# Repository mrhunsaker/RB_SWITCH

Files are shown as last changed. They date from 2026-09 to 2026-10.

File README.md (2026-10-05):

# RB Switch









The RB Switch is a three-button Bluetooth Low Energy (BLE) accessibility switch. It presents itself to a computer, tablet, or phone as a standard Bluetooth keyboard, so it works with Switch Control (iOS/iPadOS), Switch Access (Android), and any app that accepts keyboard input.

## At a glance

| | |
|---|---|
| **Buttons** | SW1 Left Arrow, SW2 Enter, SW3 Right Arrow |
| **Bluetooth name** | RB Switch |
| **Microcontroller** | ESP32-S3-MINI-1-N4R2 |
| **Power** | USB-C or a single-cell Li-Po battery. No power switch and no sleep mode. |
| **Charging** | MCP73831, about 500 mA. D1 lights while charging. |
| **Regulator** | TPS63001 3.3 V buck-boost |
| **PCB** | KiCad 10, 4 layers, 115 × 38 mm |
| **Firmware** | Arduino sketch using NimBLE-Arduino 2.x |

## Quick start

1. Power the switch from USB-C or its battery.
2. Pair **RB Switch** in the device's Bluetooth settings.
3. Press each button in a text field: Left, Enter, Right.
4. Set up Switch Control (iOS/iPadOS) or Switch Access (Android) from the guides below.

**Important for Android users:** Android's Switch Access is a separate app you install/update from the Google Play Store, and its setup wizard only offers a one-switch or two-switch configuration. It does not offer a third switch by default. Using the RB Switch's third button on Android requires one extra step beyond the wizard. This is different from iOS/iPadOS, where all three buttons can be assigned directly in the normal setup flow. See [Android Switch Access](docs/switch-access-android.md) and [iOS/iPadOS Switch Control](docs/switch-control-ios.md) before you configure a device.

## Production firmware

The production firmware is:

`firmware/RB_SWITCH_firmware/RB_SWITCH_firmware.ino`

### Button mapping

| Switch | GPIO | Keyboard key |
| --- | ---:| --- |
| SW1 | GPIO10 | Left Arrow |
| SW2 | GPIO11 | Enter |
| SW3 | GPIO12 | Right Arrow  |

Each button press produces one key press followed by one key release. Holding a button does not repeat the key. A press made while no host is connected is ignored.

### Building the firmware

1. Install the Arduino IDE, the **ESP32 Arduino core** by Espressif, and **NimBLE-Arduino 2.x**.
2. Select **ESP32S3 Dev Module** and set **USB CDC On Boot** to **Enabled**.
3. Open the `.ino` file, click **Verify**, then **Upload** over a data-capable USB-C cable. If the upload does not start, hold BOOT, tap RESET, release BOOT.
4. Open the Serial Monitor at 115200 baud.

See [Firmware](docs/firmware.md) for details.

## Documentation

| For | Read |
|---|---|
| Classroom staff setting up a device | [Setup & Pairing](docs/setup.md) |
| iPad and iPhone | [iOS/iPadOS Switch Control](docs/switch-control-ios.md) |
| Android phones and tablets | [Android Switch Access](docs/switch-access-android.md) |
| How the buttons behave | [Switch Operation](docs/use.md) |
| Something is not working | [Troubleshooting](docs/troubleshooting.md) |
| Evaluating a student for switch access and teaching switch skills | [Switch Evaluation Package](docs/evaluation-package.md) |
| Programming the board | [Firmware](docs/firmware.md), [Firmware Customization](docs/firmware-customization.md) |
| Hardware reference | [Hardware](docs/hardware.md) |
| Enclosure label | [QR Code](docs/qr-code.md) |

Published documentation: <https://mrhunsaker.github.io/RB_SWITCH/>

Two printable Word documents are also available. Both are generated from the matching page in `docs/`.

| Download | Source page | Use |
|---|---|---|
| [`RB_Switch_Paraprofessional_Setup_Guide.docx`](RB_Switch_Paraprofessional_Setup_Guide.docx) | `docs/setup.md` | Classroom quick-reference for pairing, setup and troubleshooting |
| [`RB_Switch_Evaluation_Package.docx`](RB_Switch_Evaluation_Package.docx) | `docs/evaluation-package.md` | Fill-in package for evaluating, teaching and documenting adaptive switch access (checklists, five-stage data sheets, graphing sheet, summary report, IEP goal bank) |

## Troubleshooting at a glance

| Symptom | First thing to try |
|---|---|
| Not in the Bluetooth list | Check power; turn Bluetooth off on other nearby devices that were paired before |
| Listed but will not connect | Forget RB Switch on the device and pair again |
| Connected, but no button works | Check it still shows Connected; a press made while disconnected is lost |
| Only two buttons work on Android | Assign the third switch under Assign switches for scanning |
| Will not power on | Charge from USB-C for 30 minutes with a known-good cable |
| Upload fails or no serial port | Hold BOOT, tap RESET, release BOOT; use a data cable |

The full guide, including board-level checks for technicians, is in [Troubleshooting](docs/troubleshooting.md).

## Hardware

The current board uses:

- ESP32-S3-MINI-1-N4R2
- Three Omron B3F-series tactile switches
- USB-C power/programming connection (native USB, no USB-to-serial chip)
- Single-cell Li-Po battery connection and MCP73831 charger
- TPS63001 3.3 V buck-boost regulator
- Battery-voltage sensing (not yet used by the firmware)
- MCP73831 charge-status LED
- Reset and boot buttons, with a 10 kΩ pull-up and 1 µF capacitor on the reset line

Hardware source files are in `electrical/`, `bom/`, and `mechanical/`.

| Path | Contents |
|---|---|
| `electrical/mechanical_switch/RB_Switch.kicad_sch`, `.kicad_pcb` | Current KiCad 10 schematic and 4-layer PCB. The schematic is fully wired and its netlist matches the PCB. |
| `electrical/mechanical_switch/VERIFICATION.md` | How the board was checked against the firmware, and what was not checked |
| `electrical/mechanical_switch/net_table.json` | Net-by-net list of pads |
| `bom/` | BOMs and placement files for JLCPCB and PCBWay, plus sourcing notes |
| `mechanical/` | Enclosure (OpenSCAD) |
| `docs/hardware.md` | Pin map and a part-by-part description of the connections |

> **Before ordering boards:** the files in `electrical/mechanical_switch/gerbers/` and the PCB images in `electrical/mechanical_switch/diagrams/` come from an earlier layout. Re-export them with `create_gerber.ps1` and check the CPL orientation of U1, REG1, D1, J_USB1, and L1 in the fab's preview.

## Production scope

The production design has three mechanical switch inputs only. It does not implement touch sensors, proximity sensors, NeoPixel/RGB indicators, mono-jack inputs, or the earlier F-key input mapping.

The charge-status LED (D1) is controlled by the battery charger and is not a programmable RGB LED.

## Repository layout

| Path | Contents |
|---|---|
| `firmware/RB_SWITCH_firmware/` | Production sketch |
| `firmware/BLE_ADAPTIVE_SWITCH_EXPANDED_SCAFFOLD/` | Archived earlier firmware, not production |
| `electrical/` | KiCad project, gerbers, diagrams, verification notes |
| `bom/` | BOM, placement and sourcing files |
| `mechanical/` | Enclosure and storage box models |
| `docs/` | GitHub Pages source |
| `documents/` | Packaging-friendly copy of `docs/` |
| `tools/` | Scripts that keep `documents/` and the printable Word documents in sync with `docs/` |
| `RB_Switch_Paraprofessional_Setup_Guide.docx` | Printable classroom guide |
| `RB_Switch_Evaluation_Package.docx` | Printable switch evaluation package |
| `CHANGES.md` | Changelog |

## Documentation source

`docs/` is the published GitHub Pages source.

`documents/` contains the same documentation in a packaging-friendly directory. Keep the two documentation sets synchronized when documentation changes.

After editing `docs/`, run:

```
python3 tools/sync_documents.py
node tools/build_docx.js
```

The first script rewrites `documents/` from `docs/`. The second rebuilds both Word documents (`RB_Switch_Paraprofessional_Setup_Guide.docx` from `docs/setup.md` and `RB_Switch_Evaluation_Package.docx` from `docs/evaluation-package.md`). It needs Node.js and the `docx` package (`npm install docx`). Pass `setup` or `evaluation` to build just one. See [tools/README.md](tools/README.md).

## GitHub Pages and enclosure QR code

Publish `docs/` with GitHub Pages. The enclosure QR code should point to the published documentation home page. See [QR Code](docs/qr-code.md).

## Contributing

Contributions to firmware, hardware, and documentation are welcome. See [CONTRIBUTING.md](CONTRIBUTING.md) for project structure, how to propose a change, and pull request expectations, and [CODE_STYLE.md](CODE_STYLE.md) for formatting and naming conventions. Please review [CODE_OF_CONDUCT.md](CODE_OF_CONDUCT.md) before participating.

## Security

To report a suspected security or safety issue, see [SECURITY.md](SECURITY.md) rather than opening a public issue.

## Changelog

See [CHANGES.md](CHANGES.md) for a history of notable changes.

## License

This project is licensed under the APACHE 2.0 License— see [LICENSE](LICENSE) for the full text, including a note on hardware-specific licensing alternatives.

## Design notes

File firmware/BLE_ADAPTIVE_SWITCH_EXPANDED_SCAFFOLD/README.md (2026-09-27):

# Archived Firmware

This directory contains an earlier adaptive-switch firmware implementation retained for historical reference.

It is **not the production RB Switch firmware** and is not part of the current three-button hardware documentation.

## Current production project

Use:

`firmware/RB_SWITCH_firmware/RB_SWITCH_firmware.ino`

The production RB Switch has three mechanical switch inputs:

| Switch | GPIO | Keyboard key |
|---|---:|---|
| SW1 | GPIO10 | Left Arrow |
| SW2 | GPIO11 | Enter |
| SW3 | GPIO12 | Right Arrow |

For current setup, operation, hardware, and firmware instructions, use the repository `README.md` and the `docs/` documentation.

No instructions in this archived directory should be used to configure or manufacture the current production RB Switch.

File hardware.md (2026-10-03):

---
layout: default
title: Hardware Reference
permalink: /hardware.html
---

# Hardware Reference

This page describes the current RB Switch hardware as captured in the KiCad 10 schematic and PCB in `electrical/mechanical_switch/` (4-layer, 115 × 38 mm, last updated 2026-10-03).

The schematic and PCB were checked against each other: all 19 named nets and all 34 intentionally unused pins match pad-for-pad. See `electrical/mechanical_switch/VERIFICATION.md` for what was checked and what was not.

## User controls

| Reference | Function | Net | MCU connection |
|---|---|---|---|
| SW1 | Left Arrow | `/SW1_NET` | U1 pin 14 (IO10) → GPIO10 |
| SW2 | Enter | `/SW2_NET` | U1 pin 15 (IO11) → GPIO11 |
| SW3 | Right Arrow | `/SW3_NET` | U1 pin 16 (IO12) → GPIO12 |
| SW_RST1 | Reset | `/EN_NET` | U1 pin 45 (EN) |
| SW_BOOT1 | Boot / download mode | `/BOOT_NET` | U1 pin 4 (IO0) |

Each of SW1–SW3 connects its GPIO to ground when pressed, so the firmware uses `INPUT_PULLUP` and treats LOW as pressed. Each switch input has a 100 nF capacitor to ground (C9, C10, C11) for filtering. GPIO10–12 are not strapping pins, so a held button at boot does not change boot mode.

Reset and boot use 10 kΩ pull-ups (R5 on EN, R6 on IO0) to 3.3 V, with the switch pulling the line to ground.

## Main electronics

| Reference | Part | Function |
|---|---|---|
| U1 | ESP32-S3-MINI-1-N4R2 | BLE MCU |
| REG1 | TPS63001DRCR | 3.3 V buck-boost regulation |
| L1 | 2.2 µH, Bourns SRN4018 | Regulator inductor |
| U_CHG1 | MCP73831T-2ACI/OT | Li-Po charging |
| J_USB1 | GCT USB4105-GF-A USB-C receptacle | Power, charging and native USB |
| J_BAT1 | JST-PH 2-pin | Battery connection |
| D1 | 0603 red LED | Charge status |
| R7, R8, C8 | 100 kΩ / 100 kΩ / 100 nF | Battery-voltage sense network |

Reference designators `J_BAT1`, `J_USB1`, `SW_RST1`, `SW_BOOT1` and `U_CHG1` end in a digit so KiCad treats them as annotated. Older documents and BOMs may show them without the `1`.

## What each part connects to

**Power input and charging**

- **J_USB1:** VBUS pins (A4, A9, B4, B9) go to C4 and U_CHG1 pin 4. CC1 goes to R3 and CC2 goes to R4. D+ (A6, B6) goes to U1 pin 24 (IO20) and D− (A7, B7) goes to U1 pin 23 (IO19). All GND pins and the shield go to ground. The two SBU pins are unused.
- **R3, R4 (5.1 kΩ):** CC1 and CC2 to ground, so the port presents itself as a USB-C sink.
- **C4 (1 µF):** VBUS to ground.
- **U_CHG1 (MCP73831):** VBUS in, VBAT out to the battery rail, ground, PROG to R1, STAT to D1's cathode.
- **R1 (2 kΩ):** PROG to ground, setting about 500 mA charge current.
- **D1:** cathode to STAT, anode to R2.
- **R2 (1 kΩ):** D1's anode to 3.3 V.

**Battery and regulator**

- **J_BAT1:** pin 1 to the battery rail (VBAT), pin 2 to ground.
- **REG1 (TPS63001):** VIN, VINA and EN go to VBAT. PS/SYNC, PGND, GND and the thermal pad go to ground. L1 and L2 go to the two ends of inductor L1. VOUT and FB go to the 3.3 V rail (the TPS63001 is the fixed 3.3 V version).
- **L1:** between REG1's two switch pins.
- **C1 (10 µF):** VBAT to ground.
- **C2 (22 µF), C3 (10 µF):** 3.3 V rail to ground.

**Battery sensing**

- **R7 and R8 (100 kΩ each):** a divider from VBAT to ground. The midpoint also has C8 (100 nF) to ground and goes to U1 pin 9 (IO5).
- The production firmware does not read this input yet. It reports a fixed 100% battery level.

**Microcontroller**

- **U1:** 3.3 V on pin 3, ground on pins 1, 2, 42, 43 and 46–65 (including the exposed pad). Pins 4, 9, 14, 15, 16, 23, 24 and 45 are connected as described above. The other 32 pins are intentionally unused.
- **C5, C6 (100 nF), C7 (10 µF):** 3.3 V rail to ground, decoupling for U1.

## PCB summary

| Item | Value |
|---|---|
| Size / layers | 115 × 38 mm, 4 layers (F.Cu, In1 = GND plane, In2 = 3V3 plane, B.Cu) |
| Signal routing | 0.2 mm tracks; VBAT, L_A, L_B 0.25 mm; VBUS 0.3 mm |
| Vias | 0.5 mm pad / 0.3 mm drill |
| Fixed placement | SW1–SW3, the two M4 mounting holes (MH1, MH2) and J_USB1 |
| Antenna | The module's antenna end points toward the right edge of the board. That area has a copper keep-out on all layers, and the module's courtyard extends past the board edge. |

SW1, SW2 and SW3 sit at the same positions as in the original design (pad 1 at X = 101, 126, 151 mm; Y = 99 mm). The M4 holes are at (91, 84) and (179.5, 84). J_USB1 is at (84, 99) rotated −90°. All other parts were moved to give the tracks clearance.

MH1 and MH2 have no schematic symbol. Their footprints are marked "Not in schematic" so the parity check does not flag them.

The J_USB1 footprint has a built-in clearance of about 0.18–0.21 mm between its NPTH positioning holes and some pads. The project's minimum hole clearance is set to 0.15 mm for this reason.

## Library notes

- **U1 footprint:** the PCB uses `RF_Module:ESP32-S2-MINI-1`, the land pattern shared with the S3 module. The schematic symbol and BOM identify the part as an ESP32-S3-MINI-1-N4R2. Your KiCad library may report the S3 symbol as not found; this is a library naming issue and does not affect the board.
- **SW1–SW3 footprint:** `Button_Switch_THT:SW_TH_Tactile_Omron_B3F-100x`. Pads 1 are the pair on the top edge and connect to the switch net; pads 2 are the pair on the bottom edge and connect to ground.
- **REG1 footprint:** `Package_SON:Texas_DRC0010J`, without thermal-via pads. Four GND vias sit in the exposed pad.

## Before ordering a board

- The files in `electrical/mechanical_switch/gerbers/` and the PCB images in `electrical/mechanical_switch/diagrams/` were exported from an earlier layout. Run `create_gerber.ps1` to export fresh gerbers and renders before ordering.
- The CPL files in `bom/` were regenerated from the current PCB. Check U1, REG1, D1, J_USB1 and L1 orientation in the fab's placement preview, since no published rotation correction covers them.
- Compare the L1 land pattern with the Bourns SRN4018 datasheet. The board footprint's pad positions differ from the stock KiCad footprint.
- Verify battery polarity: J_BAT1 pin 1 is the positive terminal (VBAT).

## Hardware not included

The current PCB does not include TTP223 touch controllers, proximity sensor hardware, NeoPixel/WS2812 hardware, or 3.5 mm mono-jack switch inputs.

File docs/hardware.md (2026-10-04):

---
layout: default
title: Hardware Reference
permalink: /hardware.html
---

# Hardware Reference

This page describes the current RB Switch hardware as captured in the KiCad 10 schematic and PCB in `electrical/mechanical_switch/` (4-layer, 115 × 38 mm, last updated 2026-10-03).

The schematic and PCB were checked against each other: all 19 named nets and all 34 intentionally unused pins match pad-for-pad. See `electrical/mechanical_switch/VERIFICATION.md` for what was checked and what was not.

## User controls

| Reference | Function | Net | MCU connection |
|---|---|---|---|
| SW1 | Left Arrow | `/SW1_NET` | U1 pin 14 (IO10) → GPIO10 |
| SW2 | Enter | `/SW2_NET` | U1 pin 15 (IO11) → GPIO11 |
| SW3 | Right Arrow | `/SW3_NET` | U1 pin 16 (IO12) → GPIO12 |
| SW_RST1 | Reset | `/EN_NET` | U1 pin 45 (EN) |
| SW_BOOT1 | Boot / download mode | `/BOOT_NET` | U1 pin 4 (IO0) |

Each of SW1–SW3 connects its GPIO to ground when pressed, so the firmware uses `INPUT_PULLUP` and treats LOW as pressed. Each switch input has a 100 nF capacitor to ground (C9, C10, C11) for filtering. GPIO10–12 are not strapping pins, so a held button at boot does not change boot mode.

Reset and boot use 10 kΩ pull-ups (R5 on EN, R6 on IO0) to 3.3 V, with the switch pulling the line to ground. C12 (1 µF) from EN to ground forms an RC delay with R5 (about 10 ms), so the module stays in reset until the 3.3 V rail has settled. This is the same arrangement Espressif uses on its development boards.

## Main electronics

| Reference | Part | Function |
|---|---|---|
| U1 | ESP32-S3-MINI-1-N4R2 | BLE MCU |
| REG1 | TPS63001DRCR | 3.3 V buck-boost regulation |
| L1 | 2.2 µH, Bourns SRN4018 | Regulator inductor |
| U_CHG1 | MCP73831T-2ACI/OT | Li-Po charging |
| J_USB1 | GCT USB4105-GF-A USB-C receptacle | Power, charging and native USB |
| J_BAT1 | JST-PH 2-pin | Battery connection |
| D1 | 0603 red LED | Charge status |
| R7, R8, C8 | 100 kΩ / 100 kΩ / 100 nF | Battery-voltage sense network |
| R5, C12 | 10 kΩ / 1 µF | EN pull-up and reset-delay capacitor |

Reference designators `J_BAT1`, `J_USB1`, `SW_RST1`, `SW_BOOT1` and `U_CHG1` end in a digit so KiCad treats them as annotated. Older documents and BOMs may show them without the `1`.

## What each part connects to

**Power input and charging**

- **J_USB1:** VBUS pins (A4, A9, B4, B9) go to C4 and U_CHG1 pin 4. CC1 goes to R3 and CC2 goes to R4. D+ (A6, B6) goes to U1 pin 24 (IO20) and D− (A7, B7) goes to U1 pin 23 (IO19). All GND pins and the shield go to ground. The two SBU pins are unused.
- **R3, R4 (5.1 kΩ):** CC1 and CC2 to ground, so the port presents itself as a USB-C sink.
- **C4 (1 µF):** VBUS to ground.
- **U_CHG1 (MCP73831):** VBUS in, VBAT out to the battery rail, ground, PROG to R1, STAT to D1's cathode.
- **R1 (2 kΩ):** PROG to ground, setting about 500 mA charge current.
- **D1:** cathode to STAT, anode to R2.
- **R2 (1 kΩ):** D1's anode to 3.3 V.

**Battery and regulator**

- **J_BAT1:** pin 1 to the battery rail (VBAT), pin 2 to ground.
- **REG1 (TPS63001):** VIN, VINA and EN go to VBAT. PS/SYNC, PGND, GND and the thermal pad go to ground. L1 and L2 go to the two ends of inductor L1. VOUT and FB go to the 3.3 V rail (the TPS63001 is the fixed 3.3 V version).
- **L1:** between REG1's two switch pins.
- **C1 (10 µF):** VBAT to ground.
- **C2 (22 µF), C3 (10 µF):** 3.3 V rail to ground.

**Battery sensing**

- **R7 and R8 (100 kΩ each):** a divider from VBAT to ground. The midpoint also has C8 (100 nF) to ground and goes to U1 pin 9 (IO5).
- The production firmware does not read this input yet. It reports a fixed 100% battery level.

**Microcontroller**

- **U1:** 3.3 V on pin 3, ground on pins 1, 2, 42, 43 and 46–65 (including the exposed pad). Pins 4, 9, 14, 15, 16, 23, 24 and 45 are connected as described above. The other 32 pins are intentionally unused.
- **C5, C6 (100 nF), C7 (10 µF):** 3.3 V rail to ground, decoupling for U1.
- **C12 (1 µF):** EN (pin 45) to ground, the reset-delay capacitor described above.

## PCB summary

| Item | Value |
|---|---|
| Size / layers | 115 × 38 mm, 4 layers (F.Cu, In1 = GND plane, In2 = 3V3 plane, B.Cu) |
| Signal routing | 0.2 mm tracks; VBAT, L_A, L_B 0.25 mm; VBUS 0.3 mm |
| Vias | 0.5 mm pad / 0.3 mm drill |
| Fixed placement | SW1–SW3, the two M4 mounting holes (MH1, MH2) and J_USB1 |
| Antenna | The module's antenna end points toward the right edge of the board. That area has a copper keep-out on all layers, and the module's courtyard extends past the board edge. |

SW1, SW2 and SW3 sit at the same positions as in the original design (pad 1 at X = 101, 126, 151 mm; Y = 99 mm). The M4 holes are at (91, 84) and (179.5, 84). J_USB1 is at (84, 99) rotated −90°. All other parts were moved to give the tracks clearance.

MH1 and MH2 have no schematic symbol. Their footprints are marked "Not in schematic" so the parity check does not flag them.

The J_USB1 footprint has a built-in clearance of about 0.18–0.21 mm between its NPTH positioning holes and some pads. The project's minimum hole clearance is set to 0.15 mm for this reason.

## Library notes

- **U1 footprint:** the PCB uses `RF_Module:ESP32-S2-MINI-1`, the land pattern shared with the S3 module. The schematic symbol and BOM identify the part as an ESP32-S3-MINI-1-N4R2. Your KiCad library may report the S3 symbol as not found; this is a library naming issue and does not affect the board.
- **SW1–SW3 footprint:** `Button_Switch_THT:SW_TH_Tactile_Omron_B3F-100x`. Pads 1 are the pair on the top edge and connect to the switch net; pads 2 are the pair on the bottom edge and connect to ground.
- **L1 footprint:** `Inductor_SMD:L_Bourns-SRN4018`. Its pads (1.5 × 3.6 mm, 4.55 mm overall width) match the recommended layout in the Bourns SRN4018 datasheet. The SRN4018-2R2M is at most 1.88 mm tall, well under the enclosure's clearance above the board.
- **REG1 footprint:** `Package_SON:Texas_DRC0010J`, without thermal-via pads. Four GND vias sit in the exposed pad.

## Debugging a board

Measurement points, expected voltages and a symptom guide are in [Troubleshooting, Section 6]({{ '/troubleshooting.html#6-board-level-checks-for-technicians' | relative_url }}).

## Before ordering a board

- The files in `electrical/mechanical_switch/gerbers/` and the PCB images in `electrical/mechanical_switch/diagrams/` were exported from an earlier layout. Run `create_gerber.ps1` to export fresh gerbers and renders before ordering.
- The CPL files in `bom/` were regenerated from the current PCB. Check U1, REG1, D1, J_USB1 and L1 orientation in the fab's placement preview, since no published rotation correction covers them.
- Verify battery polarity: J_BAT1 pin 1 is the positive terminal (VBAT).

## Hardware not included

The current PCB does not include TTP223 touch controllers, proximity sensor hardware, NeoPixel/WS2812 hardware, or 3.5 mm mono-jack switch inputs.

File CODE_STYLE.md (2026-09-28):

# Code Style

This document describes the conventions used across RB Switch's firmware, documentation, and hardware source files. It reflects the style already used in the production sketch and published docs — match what's already there rather than introducing a new convention, unless you're proposing a repo-wide change (open an issue first; see `CONTRIBUTING.md`).

## Firmware (`.ino` / C++)

- **Naming:**
  - Constants use `UPPER_SNAKE_CASE` with `static constexpr`, typed explicitly (`uint8_t`, `uint32_t`), for example: `static constexpr uint8_t SW1_PIN = 10;`.
  - Functions and variables use `camelCase` (`updateSwitch`, `sendKey`, `lastChangeMs`).
  - Types (structs, classes) use `PascalCase` (`SwitchState`, `ServerCallbacks`).
- **Comments:**
  - Use a block comment at the top of the file describing purpose, hardware inputs, and what is deliberately *not* included — this project has a history of scope creep from earlier prototypes, and the header comment is where that boundary is stated (see the existing header for the pattern).
  - Use `// -----...-----` banner comments to separate logical sections (pin map, BLE state, debounce state, BLE setup, switch handling, Arduino setup/loop), matching the existing file.
  - Comment *why*, not just *what*, especially for magic numbers (for example, the existing comment explaining `DEBOUNCE_MS` and the HID Usage ID table above the key constants).
- **Formatting:**
  - Two-space indentation.
  - Braces on the same line as the statement (`if (...) {`), matching the existing file.
  - One statement per line; avoid combining multiple side effects into one line even when C++ allows it.
- **Structure:**
  - Keep `loop()` non-blocking. Avoid adding `delay()` calls inside `loop()` beyond the existing 1 ms yield; use the existing millis()-based debounce pattern (`SwitchState.lastChangeMs`) as the template for any new timed behavior.
  - Keep hardware constants (pins, keys, timing) declared together near the top of the file, not scattered through the logic.
  - Prefer extending the existing `SwitchState` pattern for new inputs over introducing a parallel, differently-shaped mechanism.
- **Scope discipline:** do not add functionality outside the three-mechanical-switch production scope (touch sensors, proximity sensors, NeoPixel/RGB control, mono-jack inputs) to the production sketch. Experimental variants belong in a separate, clearly-labeled directory (see how `firmware/BLE_ADAPTIVE_SWITCH_EXPANDED_SCAFFOLD/` is marked archived), not folded into `RB_SWITCH_firmware.ino`.
- See `docs/firmware-customization.md` for guidance on which specific parts of the file are safe to change.

## Documentation (Markdown)

- **Front matter:** every page in `docs/` starts with:
  ```yaml
  ---
  layout: default
  title: <Page Title>
  permalink: /<slug>.html
  ---
  ```
  The matching page in `documents/` omits the `permalink` line (see `CONTRIBUTING.md` for why the two directories differ).
- **Headings:** one `#` H1 matching the page title, then `##` for major sections, `###` for subsections. Don't skip levels.
- **Cross-links:**
  - In `docs/`, link to other pages with `[Label]({{ '/slug.html' | relative_url }})` (add `#anchor` inside the quoted string if linking to a section).
  - In `documents/`, link with plain `[Label](slug.md)`.
- **Tables** for any fixed mapping (pin/key tables, comparison tables, HID Usage ID references) rather than prose lists — this project documents several small fixed mappings, and tables scan faster for the classroom staff and technicians who are this project's primary documentation audience.
- **Numbered steps** for anything the reader performs in order (pairing, wizard steps); **bullet lists** for unordered facts or checklists (battery-safety checklist, "what's not included" lists).
- **Troubleshooting entries** are phrased as a short symptom heading (`## Button repeats unexpectedly`) followed by either numbered diagnostic steps or a bullet checklist — not narrative prose.
- **Bold** is used for UI labels the reader taps or clicks (`**Settings → Accessibility → Switch Access**`), and for the specific button/action being referenced (`**SW1**`, `**Select**`). Avoid bolding entire sentences.
- **Platform accuracy:** when documenting OS-level accessibility menu steps (Switch Access, Switch Control, or similar), verify against a current, dated source rather than memory before publishing — these menus change between OS releases, and stale steps are worse than no steps. Note menu-wording variance explicitly rather than presenting one OEM's wording as universal.
- **Keep `docs/` and `documents/` synchronized.** See `CONTRIBUTING.md`.

## Hardware sources

- **KiCad (`electrical/`):** keep reference designators consistent with the schematic when adding parts (next available number in the existing series, for example `R9` if `R8` is the highest resistor reference). Regenerate gerbers from the same KiCad project version noted in the PR rather than hand-editing Gerber files.
- **OpenSCAD (`mechanical/`):** name revision files with an explicit revision suffix (matching the existing `enclosure_mechanical_RevD2.scad` pattern) rather than overwriting a prior revision in place, so past revisions remain buildable for reference.
- **BOM (`bom/`):** keep reference designators and part values consistent with the schematic; update the BOM in the same pull request as any schematic change that adds, removes, or substitutes a part.

## Commit messages and pull requests

See the "Submitting a pull request" and "Commit messages" sections of `CONTRIBUTING.md`.

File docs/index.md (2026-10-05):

---
layout: default
title: RB Switch
---

# RB Switch

The **RB Switch** is a three-button Bluetooth Low Energy (BLE) accessibility switch. It presents itself to a computer, tablet, or phone as a standard Bluetooth keyboard, so it works with Switch Control (iOS/iPadOS), Switch Access (Android), and any app that accepts keyboard input.

## Button functions

| Physical switch | MCU GPIO | Keyboard key |
|---|---:|---|
| **SW1** (left) | GPIO10 | **Left Arrow** |
| **SW2** (center) | GPIO11 | **Enter** |
| **SW3** (right) | GPIO12 | **Right Arrow** |

Each button press sends one key press followed by one key release. Holding a button does not repeat the key.

## Quick start

1. Power the RB Switch using USB-C or the installed single-cell Li-Po battery. There is no power switch; it is on whenever it has power.
2. Open Bluetooth settings on the device you want to use.
3. Select **RB Switch**.
4. Complete pairing if prompted.
5. Test SW1, SW2, and SW3 in a text field.
6. If using Switch Control (iOS/iPadOS) or Switch Access (Android), add the buttons as external switches. **Android and iOS/iPadOS handle a 3-button switch differently**. See [Setup & Pairing]({{ '/setup.html' | relative_url }}) before you configure scanning.

Something not working? Go to [Troubleshooting]({{ '/troubleshooting.html' | relative_url }}).

## Which page do I need?

| I am… | Start with |
|---|---|
| A paraprofessional or teacher setting up a student's device | [Setup & Pairing]({{ '/setup.html' | relative_url }}) (a printable version is available on that page) |
| Setting up an iPad or iPhone | [iOS/iPadOS Switch Control]({{ '/switch-control-ios.html' | relative_url }}) |
| Setting up an Android phone or tablet | [Android Switch Access]({{ '/switch-access-android.html' | relative_url }}) |
| Looking for how the buttons behave | [Switch Operation]({{ '/use.html' | relative_url }}) |
| Fixing a problem | [Troubleshooting]({{ '/troubleshooting.html' | relative_url }}) |
| Evaluating a student for switch access, or teaching and documenting switch skills | [Switch Evaluation Package]({{ '/evaluation-package.html' | relative_url }}) (a printable Word version is available on that page) |
| Programming the board | [Firmware]({{ '/firmware.html' | relative_url }}) and [Firmware Customization]({{ '/firmware-customization.html' | relative_url }}) |
| Building, repairing, or ordering boards | [Hardware]({{ '/hardware.html' | relative_url }}) |
| Printing the enclosure label | [QR Code]({{ '/qr-code.html' | relative_url }}) |

## Current hardware

The current board uses an ESP32-S3-MINI-1-N4R2, three Omron B3F-series tactile switches, USB-C, a Li-Po battery connection and charger, a 3.3 V buck-boost regulator, battery-voltage sensing, and a charger-status LED.

The production design has three mechanical switch inputs. Touch sensors, proximity sensors, NeoPixel/RGB indicators, mono-jack inputs, and legacy F-key mappings are not part of the production design.

## Documentation

- [Setup & Pairing]({{ '/setup.html' | relative_url }})
- [Android Switch Access]({{ '/switch-access-android.html' | relative_url }})
- [iOS/iPadOS Switch Control]({{ '/switch-control-ios.html' | relative_url }})
- [Switch Operation]({{ '/use.html' | relative_url }})
- [Firmware]({{ '/firmware.html' | relative_url }})
- [Firmware Customization]({{ '/firmware-customization.html' | relative_url }})
- [Hardware]({{ '/hardware.html' | relative_url }})
- [Troubleshooting]({{ '/troubleshooting.html' | relative_url }})
- [Switch Evaluation Package]({{ '/evaluation-package.html' | relative_url }})
- [QR Code]({{ '/qr-code.html' | relative_url }})

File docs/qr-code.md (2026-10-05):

---
layout: default
title: QR Code
permalink: /qr-code.html
---

# QR Code for the RB Switch

The enclosure QR code should open the published RB Switch documentation home page.

## QR destination

Use the final GitHub Pages URL for this repository:

`https://mrhunsaker.github.io/RB_SWITCH/`

The QR code should point to the published home page, not a local development address or temporary file. If the repository is renamed or moved, regenerate the code and update this page.

## Home page contents

The home page links to Setup & Pairing, Switch Operation, Firmware, Hardware, Troubleshooting, the Switch Evaluation Package, and this QR Code page.

## Enclosure label

A suitable label is:

**RB Switch**  
**Scan for instructions**

Place the QR code where it can be scanned without opening the enclosure.

## Printing tips

- Print the code at least 20 mm × 20 mm, with a blank margin of at least 4 modules (the small squares) on every side.
- Use black on white, or very dark on very light. Avoid low-contrast colors and glossy finishes that reflect light.
- Use a medium or high error-correction level so the code still scans if the label is scuffed.
- Test the finished label with at least one iPhone camera and one Android camera before attaching it.
- Keep the label flat. Avoid placing it over a seam or a curved edge.

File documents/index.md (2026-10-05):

---
layout: default
title: RB Switch
---

# RB Switch

The **RB Switch** is a three-button Bluetooth Low Energy (BLE) accessibility switch. It presents itself to a computer, tablet, or phone as a standard Bluetooth keyboard, so it works with Switch Control (iOS/iPadOS), Switch Access (Android), and any app that accepts keyboard input.

## Button functions

| Physical switch | MCU GPIO | Keyboard key |
|---|---:|---|
| **SW1** (left) | GPIO10 | **Left Arrow** |
| **SW2** (center) | GPIO11 | **Enter** |
| **SW3** (right) | GPIO12 | **Right Arrow** |

Each button press sends one key press followed by one key release. Holding a button does not repeat the key.

## Quick start

1. Power the RB Switch using USB-C or the installed single-cell Li-Po battery. There is no power switch; it is on whenever it has power.
2. Open Bluetooth settings on the device you want to use.
3. Select **RB Switch**.
4. Complete pairing if prompted.
5. Test SW1, SW2, and SW3 in a text field.
6. If using Switch Control (iOS/iPadOS) or Switch Access (Android), add the buttons as external switches. **Android and iOS/iPadOS handle a 3-button switch differently**. See [Setup & Pairing](setup.md) before you configure scanning.

Something not working? Go to [Troubleshooting](troubleshooting.md).

## Which page do I need?

| I am… | Start with |
|---|---|
| A paraprofessional or teacher setting up a student's device | [Setup & Pairing](setup.md) (a printable version is available on that page) |
| Setting up an iPad or iPhone | [iOS/iPadOS Switch Control](switch-control-ios.md) |
| Setting up an Android phone or tablet | [Android Switch Access](switch-access-android.md) |
| Looking for how the buttons behave | [Switch Operation](use.md) |
| Fixing a problem | [Troubleshooting](troubleshooting.md) |
| Evaluating a student for switch access, or teaching and documenting switch skills | [Switch Evaluation Package](evaluation-package.md) (a printable Word version is available on that page) |
| Programming the board | [Firmware](firmware.md) and [Firmware Customization](firmware-customization.md) |
| Building, repairing, or ordering boards | [Hardware](hardware.md) |
| Printing the enclosure label | [QR Code](qr-code.md) |

## Current hardware

The current board uses an ESP32-S3-MINI-1-N4R2, three Omron B3F-series tactile switches, USB-C, a Li-Po battery connection and charger, a 3.3 V buck-boost regulator, battery-voltage sensing, and a charger-status LED.

The production design has three mechanical switch inputs. Touch sensors, proximity sensors, NeoPixel/RGB indicators, mono-jack inputs, and legacy F-key mappings are not part of the production design.

## Documentation

- [Setup & Pairing](setup.md)
- [Android Switch Access](switch-access-android.md)
- [iOS/iPadOS Switch Control](switch-control-ios.md)
- [Switch Operation](use.md)
- [Firmware](firmware.md)
- [Firmware Customization](firmware-customization.md)
- [Hardware](hardware.md)
- [Troubleshooting](troubleshooting.md)
- [Switch Evaluation Package](evaluation-package.md)
- [QR Code](qr-code.md)

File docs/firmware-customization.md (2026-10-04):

---
layout: default
title: Firmware Customization
permalink: /firmware-customization.html
---

# Firmware Customization

This page is for anyone who needs to change what `RB_SWITCH_firmware.ino` actually does — remap a key, change debounce timing, rename the Bluetooth device, or adapt the firmware to a specific student's needs. If you only need to **install** the unmodified production firmware, see [Firmware]({{ '/firmware.html' | relative_url }}) instead. If you need to set up switch **scanning software** on the receiving device, see [Setup & Pairing]({{ '/setup.html' | relative_url }}).

This page assumes you have already installed the Arduino IDE, the ESP32 Arduino core, and the NimBLE-Arduino library, and that you can already open, verify, and upload the unmodified production sketch (see [Firmware]({{ '/firmware.html' | relative_url }})).

## Before you change anything

- Work from a copy. Duplicate `firmware/RB_SWITCH_firmware/RB_SWITCH_firmware.ino` into a new sketch folder (Arduino requires the `.ino` file name to match its parent folder name) rather than editing the production file in place, unless you intend the change to become the new production behavior.
- Change one thing at a time, re-verify, re-upload, and re-test with the Serial Monitor before making a second change. The firmware is small and single-purpose; most bugs come from stacking several changes before testing any of them.
- Keep a copy of the original file. If you're using git, commit before you start editing so you can diff or revert.

## Map of the file

| Section | What it controls | Typically safe to change? |
|---|---|---|
| `SW1_PIN`, `SW2_PIN`, `SW3_PIN` constants | Which GPIO each switch reads | Yes, if you also update the wiring/schematic to match |
| `LEFT_ARROW`, `ENTER_KEY`, `RIGHT_ARROW` constants | Which HID key each switch sends | Yes — this is the most common customization |
| `DEBOUNCE_MS` constant | How long a signal must be stable before it counts as a press | Yes, in small increments |
| `SwitchState sw1/sw2/sw3` struct instances | Binds each pin to its key and debounce state | Yes, alongside the constants above |
| `sendKey()` | Builds and sends the BLE HID press/release report, including the 20 ms hold between them | Only with care — see [Changing the key-hold timing](#changing-the-key-hold-timing) |
| `setupBLE()` | Device name, advertised HID service, report descriptor, power level | Only the device name and power level are routine changes — see below |
| `updateSwitch()` | Debounce and edge-detection logic | Not recommended unless you understand the state machine; changing this can reintroduce switch bounce |
| `setup()` / `loop()` | Pin modes, startup logging, main loop | Safe to add serial logging; avoid adding blocking `delay()` calls inside `loop()` |

## Common customization: remapping a key

The three constants near the top of the file are the usual starting point:

```cpp
static constexpr uint8_t LEFT_ARROW  = 0x50;
static constexpr uint8_t ENTER_KEY   = 0x28;
static constexpr uint8_t RIGHT_ARROW = 0x4F;
```

These are USB HID Usage IDs, not ASCII characters. To remap a button, replace the constant with a different Usage ID and, if you want the name to keep making sense, rename the constant and the comments that reference it. A short reference of commonly useful codes:

| Key | HID Usage ID |
|---|---:|
| Enter / Return | `0x28` |
| Escape | `0x29` |
| Tab | `0x2B` |
| Space | `0x2C` |
| Right Arrow | `0x4F` |
| Left Arrow | `0x50` |
| Down Arrow | `0x51` |
| Up Arrow | `0x52` |
| A–Z | `0x04`–`0x1D` (A=0x04, B=0x05, … Z=0x1D) |
| 1–0 (top row) | `0x1E`–`0x27` |

For the full table, search for "USB HID Usage Tables" (Usage Page 0x07, Keyboard/Keypad) — the constants above are drawn directly from that specification, and the firmware's report descriptor already declares the full `0x00`–`0x73` range as valid, so most standard keys work without changing `setupBLE()`.

**Why you might do this:** the most common reason is adapting the RB Switch to a specific accessibility workflow rather than the default Left Arrow / Enter / Right Arrow text-navigation mapping. For example, some Switch Access or Switch Control configurations read more naturally if the "select" button sends **Space** instead of **Enter**, or if a two-switch Android configuration is simplified by making both remaining buttons send the *same* key (for example, both edge switches send Tab) so that either hand can trigger the same scanning action. If you do this, update `docs/use.md` and `docs/hardware.md` (or your local equivalents) so the documented button map stays accurate — see [Keeping documentation in sync](#keeping-documentation-in-sync).

## Changing debounce timing

```cpp
static constexpr uint32_t DEBOUNCE_MS = 35;
```

This is the minimum time a signal must stay stable before the firmware treats it as a real press. 35 ms is a reasonable default for the Omron B3F-series tactile switches used on the production PCB. If a student's motor pattern causes intermittent double-presses, increasing this value (try 50–75 ms in small steps) is a reasonable first troubleshooting step before assuming a hardware fault. If you increase it substantially (past roughly 100 ms), very fast intentional double-taps may start being merged into one press — test with the actual student, not just yourself.

## Changing the Bluetooth device name

```cpp
NimBLEDevice::init("RB Switch");
...
hid->setManufacturer("RB Switch");
...
advertisementData.setName("RB Switch");
```

All three of these should be changed together (for example, to distinguish two units in the same classroom, such as `"RB Switch 2"`). Every unit advertises as plain "RB Switch" by default, so giving each classroom unit its own name is the simplest way to tell them apart. If you change the name, also update the physical label/sticker on the enclosure and the [QR Code]({{ '/qr-code.html' | relative_url }}) destination if it references the device name, and re-pair any devices that had the old name saved. Also forget the old name on each host and clear the stored pairings on the RB Switch (see [Troubleshooting]({{ '/troubleshooting.html#clearing-the-rb-switchs-stored-pairings' | relative_url }})).

## Changing the key-hold timing

```cpp
delay(20);
```

inside `sendKey()` controls how long the "key down" HID report is held before the "key up" report is sent. 20 ms is well within what any host OS expects for a single keypress. Shortening this is not recommended — some hosts debounce very short HID reports and may drop the keystroke entirely. If a receiving app seems to miss presses under load, try lengthening this value slightly (30–40 ms) before changing anything else.

## Adding a fourth input (advanced)

The production PCB and firmware are deliberately three-switch. If you are prototyping an expansion (for example, testing a 4th mechanical input on a breadboard before considering a hardware revision):

1. Pick an unused GPIO that is not one of GPIO10/11/12, is not already used on the board (GPIO0 BOOT, GPIO5 battery sense, GPIO19/20 USB, EN reset), and is not reserved for USB, flash, or strapping on the ESP32-S3-MINI-1-N4R2 module — check the module's datasheet before choosing.
2. Add a new `SwitchState` instance following the existing `sw1`/`sw2`/`sw3` pattern.
3. Add a matching `pinMode(..., INPUT_PULLUP)` call in `setup()`.
4. Add a matching `updateSwitch(...)` call in `loop()`.
5. Add the new HID Usage ID constant.

This is firmware-only prototyping guidance. It does **not** reflect the production hardware described in [Hardware]({{ '/hardware.html' | relative_url }}), and a fourth input has no footprint on the current PCB. Do not describe a modified sketch as "the production firmware" in documentation, labels, or support conversations — see the "Hardware not included" section of [Hardware]({{ '/hardware.html' | relative_url }}) and the archived-firmware note in `firmware/BLE_ADAPTIVE_SWITCH_EXPANDED_SCAFFOLD/README.md` for why this distinction matters to this project.

## Verifying a change

After any edit:

1. **Verify** (checkmark icon) before uploading, to catch syntax errors early.
2. **Upload** over a data-capable USB-C cable.
3. Open **Serial Monitor** at 115200 baud. Confirm the startup banner still prints the mapping you expect.
4. Press each physical button and confirm the Serial Monitor logs `SW GPIOx -> HID 0xYY` for the GPIO/key pair you intended.
5. Pair with a real host device and repeat the plain-text-field test from [Setup & Pairing, Section 4]({{ '/setup.html#4-test-the-three-buttons' | relative_url }}).
6. Only after that, re-test inside Switch Access or Switch Control if the change affects how the device should be scanned (see [Android Switch Access]({{ '/switch-access-android.html' | relative_url }}) or [iOS/iPadOS Switch Control]({{ '/switch-control-ios.html' | relative_url }})).

If something goes wrong after a change, see [Troubleshooting]({{ '/troubleshooting.html#5-firmware-upload-and-serial-monitor' | relative_url }}).

## Keeping documentation in sync

If a firmware change alters the button mapping, debounce timing, or device name from what's documented, update all of the following so a future maintainer isn't misled by a stale table:

- `README.md`
- `docs/index.md` and `documents/index.md`
- `docs/use.md` and `documents/use.md`
- `docs/setup.md` and `documents/setup.md`, then rebuild `RB_Switch_Paraprofessional_Setup_Guide.docx` (see the README)
- `docs/hardware.md` and `documents/hardware.md` (if the wiring itself changed)
- The firmware's own header comment and `Serial.println()` startup banner

See [CONTRIBUTING.md](https://github.com/mrhunsaker/RB_SWITCH/blob/main/CONTRIBUTING.md) in the repository root for the full documentation-sync expectation for pull requests.

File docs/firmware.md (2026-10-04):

---
layout: default
title: Firmware
permalink: /firmware.html
---

# Firmware

## Production firmware

The production sketch is:

`firmware/RB_SWITCH_firmware/RB_SWITCH_firmware.ino`

The sketch is self-contained and does not require a project-specific header file.

## Required software

For firmware maintenance, install:

- Arduino IDE
- ESP32 Arduino core by Espressif
- NimBLE-Arduino, **version 2.x** (the sketch uses the 2.x callback signatures, so 1.x will not compile)

No touch-sensor, proximity-sensor, NeoPixel, or separate project-specific HID library is required.

## Board selection

For the production ESP32-S3 module, select:

**ESP32 Arduino → ESP32S3 Dev Module**

Use the board settings required by the exact production module.

The board has no separate USB-to-serial chip. USB-C connects directly to the ESP32-S3's native USB (D− on GPIO19, D+ on GPIO20), so firmware is uploaded and the Serial Monitor is read over that same connection. In the Arduino IDE **Tools** menu, set **USB CDC On Boot** to **Enabled** if you want `Serial` output to appear in the Serial Monitor.

## Uploading firmware

1. Connect the PCB with a data-capable USB-C cable.
2. Open `RB_SWITCH_firmware.ino`.
3. Select the ESP32-S3 board and set **USB CDC On Boot** to **Enabled**.
4. Select the correct serial port.
5. Click **Verify**.
6. Click **Upload**.
7. If necessary, enter the ESP32-S3 bootloader: hold BOOT, press and release RESET, then release BOOT.
8. Reset the board after upload.
9. Open the Serial Monitor at 115200 baud and confirm the startup banner appears.
10. Pair with a host and run the three-button test from [Setup & Pairing]({{ '/setup.html#4-test-the-three-buttons' | relative_url }}).

If the upload fails or no serial port appears, see [Troubleshooting]({{ '/troubleshooting.html#5-firmware-upload-and-serial-monitor' | relative_url }}).

## Serial diagnostics

Open the Serial Monitor at **115200 baud**. The firmware reports the three button mappings and logs button activity with its GPIO and HID usage ID. It also prints `BLE connected` and `BLE disconnected; restarting advertising`, and `Key ignored: BLE not connected` when a button is pressed with no host connected. The full expected output is in [Troubleshooting]({{ '/troubleshooting.html#what-the-serial-monitor-should-show' | relative_url }}).

## Hardware the firmware does not use

The board also has a battery-voltage divider on GPIO5 (VBAT ÷ 2) and a charge-status LED (D1) driven by the charger. The production firmware does not read GPIO5 and reports a fixed 100% battery level. See [Hardware]({{ '/hardware.html' | relative_url }}) for the full pin map.

## HID usage IDs

| Function | HID Usage ID |
|---|---:|
| Enter / Return | `0x28` |
| Right Arrow | `0x4F` |
| Left Arrow | `0x50` |

## Bluetooth behavior

- The advertised Bluetooth name is **RB Switch** (the same on every unit).
- The sketch advertises the standard HID service and presents a boot-compatible keyboard.
- Bonding is enabled with no passkey. Pairing data is stored in flash. To clear it, erase flash while uploading (see [Troubleshooting]({{ '/troubleshooting.html#clearing-the-rb-switchs-stored-pairings' | relative_url }})).
- After a disconnect, advertising restarts automatically.
- Transmit power is set to the maximum the sketch requests (`ESP_PWR_LVL_P9`).
- There is no sleep mode, so the device draws power continuously whenever it is powered.

## Modifying the firmware

For remapping keys, changing debounce timing, renaming the device, or other customization of `RB_SWITCH_firmware.ino`, see [Firmware Customization]({{ '/firmware-customization.html' | relative_url }}).

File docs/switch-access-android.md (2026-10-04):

---
layout: default
title: Android Switch Access
permalink: /switch-access-android.html
---

# Android Switch Access with the RB Switch

This page is a deep dive into using the RB Switch's three buttons with Android's **Switch Access** feature. Read [Setup & Pairing]({{ '/setup.html' | relative_url }}) first if you haven't paired the RB Switch yet.

## Why this page exists

The RB Switch has three physical buttons (SW1 = Left Arrow, SW2 = Enter, SW3 = Right Arrow). On **iOS/iPadOS**, all three can be assigned to distinct actions directly through the normal setup flow (see [iOS/iPadOS Switch Control]({{ '/switch-control-ios.html' | relative_url }})). On **Android**, the built-in setup wizard only ever asks you to choose between a **one-switch** or **two-switch** configuration — it does not offer a "three-switch" option. This is a real, current limitation of the guided Switch Access wizard, not a bug in the RB Switch.

The good news: Android **does** support more than two switches — up to **five** — but only through settings that sit outside the wizard. This page shows how to get there.

## 1. Install Switch Access from the Google Play Store

Switch Access is no longer only a hidden feature bundled inside Android Accessibility Suite. Google now distributes it as its **own standalone app** on the Play Store.

1. Open the **Google Play Store** app.
2. Search for **Switch Access**.
3. Install the app (or tap **Update** if it's already installed but out of date).
4. Open **Settings → Accessibility**. Switch Access should now appear under **Downloaded apps** (or simply under **Accessibility**, depending on your Android version and device manufacturer).

If you skip this step, you may still find an older, more limited version of Switch Access already on the device — but it can lag behind the Play Store version in features and bug fixes. Always check the Play Store first, especially on a device that hasn't been updated recently.

## 2. Understand the wizard's one-switch / two-switch choice

After you turn on Switch Access and grant it permission, the setup wizard walks you through:

1. Choosing a switch type — select **Bluetooth switch** for the RB Switch.
2. Selecting your device from the Bluetooth list and confirming pairing.
3. Choosing **One switch** or **Two switch**.
   - **One switch**: press the switch to start scanning; press it again to select the highlighted item (auto-scan).
   - **Two switch** (recommended starting point for the RB Switch): one switch moves ("Next"), the other selects ("Select").
4. Choosing a scanning method: **Linear scanning**, **Row-column scanning**, or **Group selection**.
5. Assigning the RB Switch buttons you want to the **Next** and **Select** roles when prompted.
6. A short practice screen, then **Finish**.

At no point does this wizard ask "do you have a third switch?" That question only exists in the advanced settings screen described next.

## 3. Add the third RB Switch button (Previous)

Once the wizard is finished, go back into the settings by hand:

1. **Settings → Accessibility → Switch Access → Settings.**
2. Confirm **Auto-scan** is off (it should be, if you chose Two switch).
3. Tap **Assign switches for scanning**.
4. You will see **Next** and **Select** already assigned from the wizard. Tap **Previous**.
5. Press the remaining RB Switch button (SW1 / Left Arrow, if you used the recommended mapping below) when prompted.
6. Tap **Save**.

You can assign **up to five total switches** this way — Next, Select, Previous, Group Selection colors, and Auto-scan Reverse are all valid targets, depending on which scanning method you picked in step 4 above. For the RB Switch's three physical buttons, **Next / Select / Previous** is the natural mapping.

### Recommended mapping

| RB Switch button | Sends | Recommended Switch Access action |
|---|---|---|
| SW1 | Left Arrow | **Previous** |
| SW2 | Enter | **Select** |
| SW3 | Right Arrow | **Next** |

This mirrors the button layout printed on the enclosure (left, center, right) and the arrow-key intuition students already have from the plain-keyboard test in [Setup & Pairing]({{ '/setup.html' | relative_url }}).

If a student only needs two functions, it is entirely reasonable to stop after the wizard and leave SW1 unused on that device — nothing else needs to change, and the same RB Switch will still expose all three buttons normally to a computer, Chromebook, or iPad.

## 4. Choosing a scanning method

- **Linear scanning** moves through on-screen items one at a time (or one row at a time on a keyboard). This is the simplest method to explain to a new switch user.
- **Row-column scanning** scans by row first, then by item within the selected row. This is faster once a student is comfortable with two-step selection.
- **Group selection** requires two or more switches and divides the screen into color-coded groups; each press narrows down the selection. This method benefits the most from having a third switch assigned, since more switches mean fewer presses per selection.

Whichever method you choose, re-test all assigned buttons afterward (see [Setup & Pairing, Section 4]({{ '/setup.html#4-test-the-three-buttons' | relative_url }})).

## 5. Adjusting timing and feedback

From **Switch Access Settings**:

- **Speech, sound & vibration → Spoken feedback** reads highlighted items aloud, which can help a student who is still learning the scan pattern.
- Auto-scan timing (delay before the first item, delay between items) is adjustable if you are using the one-switch method.
- **Change Switch Access settings → [action]** lets you review or reassign any button to any action at any time, without re-running the whole wizard.

## 6. Android-specific troubleshooting

**Switch Access doesn't appear under Accessibility at all.**
Install or update the app from the Google Play Store (Step 1). On some devices it will not appear until the app has been opened at least once after installing.

**The wizard only lets me pick one or two switches, and I have three buttons.**
This is expected — see Step 3 above. The wizard is not the place to add a third switch; the **Assign switches for scanning** screen under Switch Access Settings is.

**I assigned Previous to SW1, but pressing it does nothing.**
Confirm you saved the assignment (Step 3, step 6) and that you are testing inside an app while Switch Access scanning is actually active (the screen should show a highlight box). Previous only affects the on-screen highlight; it does not undo an action that was already selected.

**Group Selection colors look confusing with three switches.**
Group Selection is most useful with three or more switches, but it does take practice. Consider starting a new student on Linear or Row-column scanning with just Next/Select, and introducing Previous or Group Selection later.

**A key on the RB Switch does something unexpected inside Switch Access, like opening a menu.**
Left Arrow, Enter, and Right Arrow are ordinary keyboard keys. If another keyboard shortcut on the device is bound to one of those keys outside of Switch Access, it can fire at the same time. Re-check the button assignment in **Assign switches for scanning**, and confirm no other keyboard-shortcut feature is intercepting the same key.

For hardware-level troubleshooting (a specific button not registering at all, on any platform), see [Troubleshooting]({{ '/troubleshooting.html' | relative_url }}).

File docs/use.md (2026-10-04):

---
layout: default
title: Switch Operation
permalink: /use.html
---

# Switch Operation

## Button map

| Button | Keyboard action |
|---|---|
| SW1 (left) | Left Arrow |
| SW2 (center) | Enter |
| SW3 (right) | Right Arrow |

This mapping is fixed in the production firmware.

## Button behavior

When a button is pressed, the firmware:

1. Reads the switch.
2. Debounces the input for 35 ms.
3. Detects the transition from released to pressed.
4. Sends the corresponding BLE HID key press.
5. Sends the corresponding BLE HID key release about 20 ms later.

A held button does not continuously repeat the key. Releasing a button sends nothing.

## Connection behavior

- The RB Switch advertises as **RB Switch** as soon as it has power. The name is the same on every unit.
- While no host is connected, button presses are ignored. They are not stored or sent later.
- If the connection drops, the RB Switch starts advertising again automatically, and a paired host normally reconnects on its own.
- One host uses the RB Switch at a time. To move it to another device, disconnect it from the first device (or turn that device's Bluetooth off), then connect from the new one.
- Pairing is stored in the RB Switch (bonding). No passkey is needed.

## Power

- The RB Switch runs from USB-C or its single-cell Li-Po battery.
- It has no power switch and no sleep mode. It is on whenever it has power.
- It reports a fixed 100% battery level to the host, so the host's battery indicator does not show the real charge.

## Electrical input behavior

The switches connect their GPIO inputs to ground when pressed.

| Signal | GPIO | Input mode | Active state |
|---|---:|---|---|
| SW1_NET | 10 | `INPUT_PULLUP` | LOW |
| SW2_NET | 11 | `INPUT_PULLUP` | LOW |
| SW3_NET | 12 | `INPUT_PULLUP` | LOW |

Each switch input has a 100 nF capacitor for hardware filtering.

## Charge-status LED

D1 is the charge-status LED controlled by the MCP73831 charger. It is on while the battery charges from USB-C and off when charging is complete or USB-C is not connected. It is not a programmable RGB LED, and it does not show button presses or the Bluetooth connection. See [Troubleshooting]({{ '/troubleshooting.html#4-power-charging-and-the-light' | relative_url }}).

## Using these buttons with accessibility scanning

The three buttons above are ordinary keyboard keys. How a host device turns them into scanning actions (Next/Previous/Select and similar) is configured on the host, not the RB Switch. **Android and iOS/iPadOS configure this differently**. See [Setup & Pairing]({{ '/setup.html' | relative_url }}), [Android Switch Access]({{ '/switch-access-android.html' | relative_url }}), and [iOS/iPadOS Switch Control]({{ '/switch-control-ios.html' | relative_url }}).

## Production scope

The current production design contains only the three mechanical switch inputs above. It does not contain or implement touch sensors, proximity sensors, NeoPixel/WS2812 RGB control, mono-jack inputs, eleven-input operation, or F1–F13 legacy mappings.

If something is not working, see [Troubleshooting]({{ '/troubleshooting.html' | relative_url }}).

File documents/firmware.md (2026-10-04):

---
layout: default
title: Firmware
---

# Firmware

## Production firmware

The production sketch is:

`firmware/RB_SWITCH_firmware/RB_SWITCH_firmware.ino`

The sketch is self-contained and does not require a project-specific header file.

## Required software

For firmware maintenance, install:

- Arduino IDE
- ESP32 Arduino core by Espressif
- NimBLE-Arduino, **version 2.x** (the sketch uses the 2.x callback signatures, so 1.x will not compile)

No touch-sensor, proximity-sensor, NeoPixel, or separate project-specific HID library is required.

## Board selection

For the production ESP32-S3 module, select:

**ESP32 Arduino → ESP32S3 Dev Module**

Use the board settings required by the exact production module.

The board has no separate USB-to-serial chip. USB-C connects directly to the ESP32-S3's native USB (D− on GPIO19, D+ on GPIO20), so firmware is uploaded and the Serial Monitor is read over that same connection. In the Arduino IDE **Tools** menu, set **USB CDC On Boot** to **Enabled** if you want `Serial` output to appear in the Serial Monitor.

## Uploading firmware

1. Connect the PCB with a data-capable USB-C cable.
2. Open `RB_SWITCH_firmware.ino`.
3. Select the ESP32-S3 board and set **USB CDC On Boot** to **Enabled**.
4. Select the correct serial port.
5. Click **Verify**.
6. Click **Upload**.
7. If necessary, enter the ESP32-S3 bootloader: hold BOOT, press and release RESET, then release BOOT.
8. Reset the board after upload.
9. Open the Serial Monitor at 115200 baud and confirm the startup banner appears.
10. Pair with a host and run the three-button test from [Setup & Pairing](setup.md#4-test-the-three-buttons).

If the upload fails or no serial port appears, see [Troubleshooting](troubleshooting.md#5-firmware-upload-and-serial-monitor).

## Serial diagnostics

Open the Serial Monitor at **115200 baud**. The firmware reports the three button mappings and logs button activity with its GPIO and HID usage ID. It also prints `BLE connected` and `BLE disconnected; restarting advertising`, and `Key ignored: BLE not connected` when a button is pressed with no host connected. The full expected output is in [Troubleshooting](troubleshooting.md#what-the-serial-monitor-should-show).

## Hardware the firmware does not use

The board also has a battery-voltage divider on GPIO5 (VBAT ÷ 2) and a charge-status LED (D1) driven by the charger. The production firmware does not read GPIO5 and reports a fixed 100% battery level. See [Hardware](hardware.md) for the full pin map.

## HID usage IDs

| Function | HID Usage ID |
|---|---:|
| Enter / Return | `0x28` |
| Right Arrow | `0x4F` |
| Left Arrow | `0x50` |

## Bluetooth behavior

- The advertised Bluetooth name is **RB Switch** (the same on every unit).
- The sketch advertises the standard HID service and presents a boot-compatible keyboard.
- Bonding is enabled with no passkey. Pairing data is stored in flash. To clear it, erase flash while uploading (see [Troubleshooting](troubleshooting.md#clearing-the-rb-switchs-stored-pairings)).
- After a disconnect, advertising restarts automatically.
- Transmit power is set to the maximum the sketch requests (`ESP_PWR_LVL_P9`).
- There is no sleep mode, so the device draws power continuously whenever it is powered.

## Modifying the firmware

For remapping keys, changing debounce timing, renaming the device, or other customization of `RB_SWITCH_firmware.ino`, see [Firmware Customization](firmware-customization.md).

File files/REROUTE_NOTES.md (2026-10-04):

> **Superseded (2026-10-03).** This note describes an earlier routing of the PCB. The current schematic, PCB and checks are in `electrical/mechanical_switch/` and `electrical/mechanical_switch/VERIFICATION.md`. Kept for history only.

# RB_Switch re-route notes

Board: 4-layer, 115 x 38 mm (In1 = GND plane, In2 = V3V3 plane).

## What was wrong
The original file had 36 tracks, each a single straight line from pad to pad (some ~100 mm long, diagonal across the board). 22 pairs crossed on the same layer (real shorts), and 58 vias were stacked on pads with overlapping annuli. Several endpoints did not land on any pad (J_USB tracks started at x=81-86, the pads are at x=87.7).

## What changed in RB_Switch.kicad_pcb
- Removed all 36 tracks and 58 vias (signal-net vias, duplicate vias, and plane vias that violated clearance or sat inside through-hole pads).
- Kept 61 plane vias (GND / V3V3) that were clean.
- Added 235 track segments (17 signal nets) and 45 vias (signal layer hops + plane fan-outs for REG1 pin 1, REG1 GND pins 3/7/9 and the USB-C GND pins).
- Widened VBUS / VBAT / L_A / L_B to 0.3-0.5 mm where clearance allowed (0.2 mm at fine-pitch pads).
- Nothing else in the file was touched (footprints, zones, outline, rules).

## Checked here (custom script, NOT KiCad DRC)
0 copper-clearance errors (0.2 mm), 0 edge-clearance errors (0.5 mm), 0 hole-to-hole errors, all 17 signal nets fully connected.
The script uses rectangular pads and ignores silkscreen, mask, courtyards and zone fill, so KiCad's DRC is the authority.

## Needs your decision: "Antenna" rule area
The rule area (x 154.25-173.75, y 76.3-121.7, all copper layers; no tracks / vias / pads / copper pour / footprints) spans the full board height. It:
- contains D1, R2, R7, C9, C10, C11 and part of SW3, so KiCad will flag them;
- must be crossed by every net between the left-hand circuitry and the ESP32 (SW1/2/3, EN, USB D+/D-, VBAT_SENSE, BOOT), so a route that respects it does not exist;
- removes the GND and V3V3 plane copper there, leaving C9.2, C10.2, C11.2, SW3.2 (GND) and R2.2 (V3V3) without a plane connection.
I routed through it and did not edit it. Shrinking it to the real antenna end of U1 should clear all of the above.

## Other observations
- L1 sits ~30 mm from REG1; the switching-node traces (L_A / L_B) are long for a buck-boost.
- About 60 GND/V3V3 pads have vias directly in the pad. Unless plugged/filled, solder can wick through; tell PCBWay or move the vias.

## Next steps
1. Open the file in KiCad, press B to refill zones, run DRC (with parity check).
2. Decide the Antenna rule area.
3. Re-export with create_gerber.ps1 and upload.

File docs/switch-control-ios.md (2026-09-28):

---
layout: default
title: iOS/iPadOS Switch Control
permalink: /switch-control-ios.html
---

# iOS/iPadOS Switch Control with the RB Switch

This page is a deep dive into using the RB Switch's three buttons with Apple's **Switch Control** accessibility feature on iPhone and iPad. Read [Setup & Pairing]({{ '/setup.html' | relative_url }}) first if you haven't paired the RB Switch yet.

## How this differs from Android

Switch Control is built into iOS/iPadOS — there is no separate app to install from the App Store. More importantly for the RB Switch, **Switch Control does not force a choice between "one switch" and "two switch" the way Android's Switch Access wizard does.** Instead, you add switches one at a time, and each new switch is assigned to whichever action you pick from a full list. Because of this, all three RB Switch buttons can be given three distinct, independent actions from the very first setup pass, with no extra steps required beyond what's already in [Setup & Pairing]({{ '/setup.html' | relative_url }}). If you're coming from an Android Switch Access setup and wondering why there's no equivalent "advanced settings" step here — there isn't one needed. See [Android Switch Access]({{ '/switch-access-android.html' | relative_url }}) for the contrast.

## Turning on Switch Control

1. Pair **RB Switch** in **Settings → Bluetooth** (see [Setup & Pairing]({{ '/setup.html' | relative_url }})).
2. Open **Settings → Accessibility → Switch Control**.
3. Turn on **Switch Control**.

The first time it's enabled, iOS may briefly show an onboarding screen. You can dismiss it and configure switches directly.

## Adding all three RB Switch buttons

1. Open **Switches → Add New Switch → External**.
2. Press the RB Switch button you want to assign first (there's no required order).
3. When prompted, choose the action for that button. Common first choices:
   - **Select Item**
   - **Move to Next Item**
   - **Move to Previous Item**
4. Tap **Add New Switch** again and repeat for the second button.
5. Repeat once more for the third button.

### Recommended mapping

| RB Switch button | Sends | Recommended Switch Control action |
|---|---|---|
| SW1 | Left Arrow | **Move to Previous Item** |
| SW2 | Enter | **Select Item** |
| SW3 | Right Arrow | **Move to Next Item** |

This mirrors the left/center/right layout of the enclosure and the arrow-key intuition students already have from the plain-keyboard test in [Setup & Pairing]({{ '/setup.html' | relative_url }}), and it maps directly onto the equivalent Android recommendation, so a student who uses both an iPad and an Android device gets a consistent physical mapping even though the two operating systems configure it differently.

Switch Control offers many more actions than these three (Long Press, Tap, gestures, scrolling, opening Control Center, running a custom "Recipe," and more). Because assignment is per-switch and not limited to a fixed set of roles, you can give any RB Switch button any of these actions if the default mapping above doesn't fit a particular student.

## Choosing a scanning style

**Settings → Accessibility → Switch Control → Scanning Style** offers:

- **Auto Scanning** — the highlight moves on its own; press a switch to select. Works with as few as one assigned switch.
- **Manual Scanning** — you press one switch to move the highlight and another to select. This is the natural fit for the RB Switch's Left/Right + Enter mapping above.
- **Single Switch Step** — a single switch both moves and (after a pause) selects.

**Auto Scanning** and **Manual Scanning** both make use of a third switch if you've assigned **Move to Previous Item**, letting a student correct an overshoot without waiting for the scan to wrap back around.

## Adjusting timing and feedback

- **Settings → Accessibility → Switch Control → Auto Scanning Time** adjusts how long each item is highlighted before Auto Scanning moves on.
- **Switch Control → Switch Stabilization** and **Switch Control → Ignore Repeat** help filter out accidental double-presses, which can be useful if a student's motor control causes brief bounces (see also the firmware-level debounce described in [Firmware]({{ '/firmware.html' | relative_url }})).
- **Switch Control → Sound Effects** and **Speech** provide audio feedback as the highlight scans, which can help a student learn the pattern before relying on vision alone.

## iOS/iPadOS-specific troubleshooting

**A button is recognized as a keypress but Switch Control never highlights anything.**
Confirm Switch Control is actually turned on (Step 1) — the RB Switch will still send Left Arrow / Enter / Right Arrow to any app whether or not Switch Control is active, which can look like "it's connected but nothing happens" if you're testing inside an app that also responds to arrow keys.

**I want to reassign a button to a different action.**
Open **Switches**, tap the existing switch entry, and choose a new action. You do not need to remove and re-add it.

**Menu wording doesn't match this page.**
Apple periodically renames or relocates Switch Control menu items between iOS/iPadOS releases. The concepts above (Switches → Add New Switch → External, per-switch action assignment, scanning style) have been stable across recent releases even when exact wording shifts.

For hardware-level troubleshooting (a specific button not registering at all, on any platform), see [Troubleshooting]({{ '/troubleshooting.html' | relative_url }}).

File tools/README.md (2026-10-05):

# Documentation tools

Two small scripts keep the documentation copies in sync. Run them from the repository root after editing anything in `docs/`.

| Script | What it does |
|---|---|
| `python3 tools/sync_documents.py` | Rewrites `documents/` from `docs/` (drops the Jekyll `permalink:` line and turns `{{ '/page.html' \| relative_url }}` links into `page.md`). Add `--check` to see whether `documents/` is stale without writing anything. |
| `node tools/build_docx.js [setup\|evaluation]` | Rebuilds the printable Word documents from `docs/`. With no argument it builds both. Needs Node.js and the `docx` package (`npm install docx`). |

## Word documents

| Output | Source |
|---|---|
| `RB_Switch_Paraprofessional_Setup_Guide.docx` | `docs/setup.md` |
| `RB_Switch_Evaluation_Package.docx` | `docs/evaluation-package.md` |

The Markdown page is the single source for each Word file. Do not edit the `.docx` by hand; your changes would be lost the next time it is rebuilt.

Comments in the Markdown control the Word output. They are invisible on the website and on GitHub.

| Comment | Effect in the Word file |
|---|---|
| `<!-- web-only -->` ... `<!-- /web-only -->` | Text between the markers is left out |
| `<!-- pagebreak -->` | Starts a new page |
| `<!-- landscape -->` / `<!-- portrait -->` | Starts a new page in that orientation (the evaluation package uses landscape for its data sheets) |

Other behavior: a blockquote that starts with **Note**, **Important**, **Tip** or **Warning** becomes a colored callout. A line made only of underscores becomes a handwriting line. Table rows that are mostly empty get extra height so they can be filled in by hand.

After rebuilding a Word file, open it and check the page breaks before printing.

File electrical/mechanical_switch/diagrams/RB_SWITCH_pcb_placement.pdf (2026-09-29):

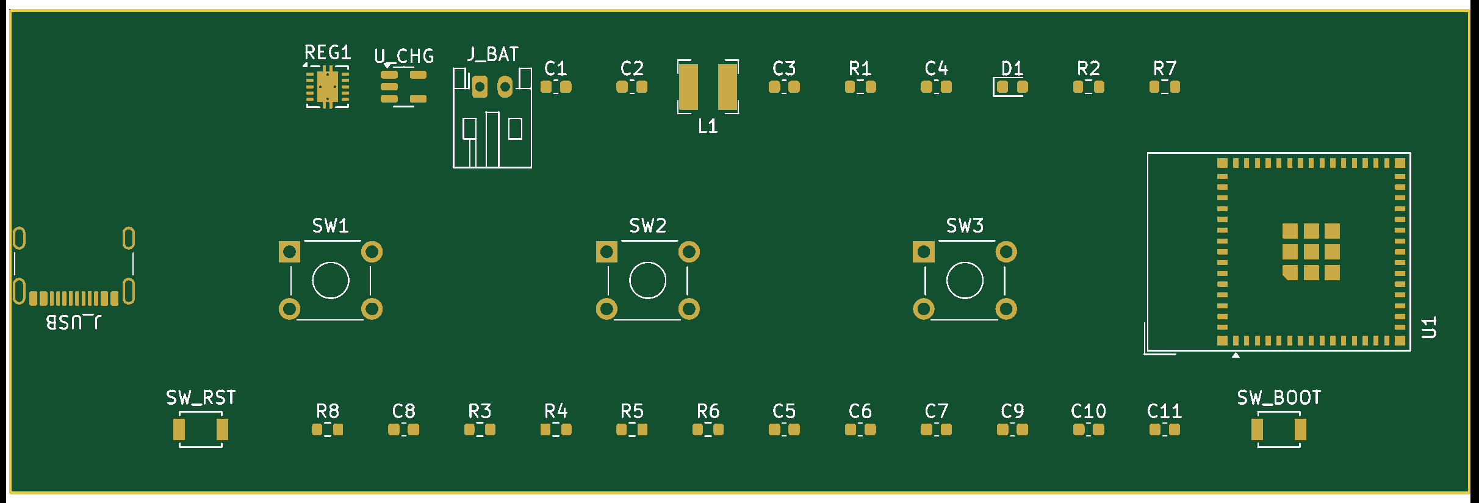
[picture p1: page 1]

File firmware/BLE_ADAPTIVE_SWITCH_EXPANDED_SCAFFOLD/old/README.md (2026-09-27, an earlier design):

---
title: Bluetooth Adaptive Switch Node
category: Accessibility
author: Michael Ryan Hunsaker, M.Ed., Ph.D.
tags: 
  - accessibility
  - switch-access
  - esp32
  - arduino
  - iOS
  - iPadOS
  - Android
footer: ${pageNo} / ${pageCount}
header: ${title} / ${author}
---

# BLE Adaptive Switch Node

**ESP32-S3 SuperMini · BLE HID Keyboard · Adaptive Switch Controller for Assistive Technology**

A Bluetooth Low Energy (BLE) HID keyboard designed for adaptive access applications. The device presents 11 independent inputs as unique HID keyboard events, enabling accessibility frameworks such as iPadOS/iOS Switch Control and Android Switch Access to identify and map each switch independently.

The firmware is optimized for assistive technology deployments where reliability, low latency, and simple configuration are more important than high input density. GPIO 3 is intentionally excluded from the design to avoid any reset-time strapping behavior.

---

[TOC]

---

# Features

- 11 independent adaptive inputs
  - 6 capacitive touch sensors
  - 1 proximity sensor
  - 4 mechanical switch inputs

- 11 unique HID key assignments
  - F1–F6
  - F8–F12

- BLE HID keyboard implementation
  - No companion application required
  - Standard Bluetooth keyboard profile

- Verified accessibility support
  - iPadOS Switch Control
  - Android Switch Access

- NimBLE Bluetooth stack
  - Reduced memory footprint
  - Fast reconnection
  - Automatic advertising restart

- Visual status indication
  - WS2812 NeoPixel on GPIO 48
  - Unique color per input

- 35 ms debounce protection

- Edge-triggered operation
  - Single event per activation
  - No auto-repeat

---

# Platform Compatibility

| Platform | Status |
|---|---|
| iPadOS Switch Control | Verified |
| iOS Switch Control | Verified |
| Android Switch Access | Verified |
| Windows | Verified |
| macOS | Verified |
| Linux | Verified |
| ChromeOS | Anticipated |

## Verified Android Device

The current firmware has been successfully tested on:

- Nokia G100
- Android 12
- Android Switch Access

The device paired as a standard BLE keyboard and successfully generated switch events without custom middleware or application software.

---

# Hardware Requirements

| Qty | Component |
|---|---|
| 1 | ESP32-S3 SuperMini |
| Up to 6 | TTP223 capacitive touch sensors |
| 1 | Supported I²C proximity sensor |
| Up to 4 | Adaptive mechanical switches |
| 1 | USB-C cable |
| 1 | 3.7V 1100mAh Lithium polymer Battery (optional) |
| 1 | TP4056 Type-c USB 5V 1A 18650 Lithium Battery Charging Board <br >with Dual Protection (optional) |

---

# Hardware Architecture

## Touch Inputs

| Input | GPIO | HID Key |
|---|---|---|
| Touch 1 | GPIO 1 | F1 |
| Touch 2 | GPIO 2 | F2 |
| Touch 3 | GPIO 4 | F3 |
| Touch 4 | GPIO 5 | F4 |
| Touch 5 | GPIO 6 | F5 |
| Touch 6 | GPIO 7 | F6 |

## Proximity Input

| Interface | GPIO | HID Key |
|---|---|---|
| I²C | SDA=8 SCL=9 | F8 |

## Mechanical Switches

| Input | GPIO | HID Key |
|---|---|---|
| Switch 1 | GPIO 10 | F9 |
| Switch 2 | GPIO 11 | F10 |
| Switch 3 | GPIO 12 | F11 |
| Switch 4 | GPIO 13 | F12 |

---

# GPIO Reference

## Reserved / Avoided Pins

| GPIO | Reason |
|---|---|
| 0 | BOOT strapping pin |
| 19 | USB D− |
| 20 | USB D+ |
| 45 | VDD_SPI strapping |
| 46 | Input-only boot strapping |
| 48 | NeoPixel LED in use |

## GPIO 3 Policy

GPIO 3 is intentionally not used.

Although functional as a digital input, it is a reset-time strapping pin. Eliminating GPIO 3 from the design avoids deployment issues and simplifies support for educational and assistive technology environments.

---

# Wiring Guide

## TTP223 Sensors

| TTP223 Pin | Connection |
|---|---|
| VCC | 3V3 |
| GND | GND |
| SIG | GPIO 1,2,4,5,6,7 on SP32-S3 Supermini |

## I²C Proximity Sensor

| Sensor Pin (APSD-9930 or APDS-9960) | Connection |
|---|---|
| VCC | 3V3 |
| GND | GND |
| SDA | GPIO 8 on ESP32-S3 Supermini |
| SCL | GPIO 9 on ESP32-S3 Supermini |

## Mechanical Adaptive Switches

Each switch connects between:

- GPIO input
- Ground

Inputs use INPUT_PULLUP internally. 

---

# HID Key Mapping

| Source | HID Key |
|---|---|
| Touch 1 (TTP223) | F1 |
| Touch 2 (TTP223) | F2 |
| Touch 3 (TTP223) | F3 |
| Touch 4 (TTP223) | F4 |
| Touch 5 (TTP223) | F5 |
| Touch 6 (TTP223) | F6 |
| Proximity (APDS-9930/9960) | F8 |
| Switch 1 (Mono Jack Input) | F9 |
| Switch 2 (Mono Jack Input) | F10 |
| Switch 3 (Mono Jack Input) | F11 |
| Switch 4 (Mono Jack Input) | F12 |

Note: F7 is intentionally unused.

---

# Bluetooth Operation

## Device Name

Default = `BT Switch`

## Behavior

- Advertises continuously until connected
- Appears as a standard BLE keyboard
- Automatically resumes advertising after disconnect
  - Does not advertise when connected. No interference if multiple units used near each other

- No proprietary protocol required

---

# Proximity Sensor Support

The firmware scaffold includes support for:

- APDS9930
- APDS9960
- VCNL4040
- VL53L0X

Sensor-specific initialization may require enabling the appropriate library and code section.

---

# Software Dependencies

Required:

- `NimBLE-Arduino`
- `Adafruit NeoPixel`
- `Wire`

Optional (sensor dependent):

- `Adafruit VCNL4040`
- `Adafruit VL53L0X`
- `SparkFun APDS9960`

---

# Build and Flash Instructions

1. Install ESP32 board support in `Arduino IDE`.
2. Select `ESP32S3 Dev Module`.
3. Open `BLE_ADAPTIVE_SWITCH_EXPANDED_SCAFFOLD.ino`.
4. Ensure `types_expanded.h` is present (should open in adjacebnt window automatically)
5. Install required libraries.
6. Connect the board using USB-C.
7. Select the correct serial port.
8. Upload the firmware.
9. Open Serial Monitor at 115200 baud.

---

# Android Configuration

1. Pair the device through Android Bluetooth settings.
2. Install `Switch Access` from the Google Play Store
3. Enable `Switch Access`.
4. Add switches through Switch Access settings.
5. Activate each physical input to register its associated HID key.
6. Assign actions as desired.

---

# iPadOS / iOS Configuration

1. Open Settings.
2. Accessibility → Switch Control.
3. Add New Switch.
4. Select External.
5. Activate a switch on the device.
6. Assign an action.
7. Repeat as required.

---

# Troubleshooting

## Device Does Not Appear

- Confirm Bluetooth advertising started.
- Verify board power.
- Remove old pairings and re-pair (it may be connecting to another computer or nearby device)

## Switch Activates Repeatedly

- Increase debounce interval.
- Check switch wiring.

## Proximity Sensor Not Detected

- Verify SDA/SCL wiring.
- Confirm correct sensor library.
- Check I²C address.

## Upload Problems

- Verify USB cable supports data.
- Select correct COM port.
- Hold BOOT if necessary during upload.

---

## CHANGE LOG

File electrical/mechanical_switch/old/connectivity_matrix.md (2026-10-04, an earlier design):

> **Superseded (2026-10-03).** This note describes an earlier routing of the PCB. The current schematic, PCB and checks are in `electrical/mechanical_switch/` and `electrical/mechanical_switch/VERIFICATION.md`. Kept for history only.

What each component connects to

## Power input and charging

J_USB (USB-C): VBUS pins go to U_CHG pin 4 and C4. CC1 goes to R3, CC2 goes to R4. D+ and D− go to U1's USB pins. All GND pins and the shield go to ground. Both SBU pins are unused.
R3, R4 (5.1 kΩ): each runs from its CC line (CC1, CC2) to ground.
C4 (1 µF): VBUS to ground, the charger's input capacitor.
U_CHG (MCP73831): VBUS in, VBAT out to the battery rail, ground, PROG to R1, STAT to D1's cathode.
R1 (2 kΩ): PROG pin to ground, which sets the charge current.
D1 (LED): cathode to U_CHG STAT, anode to R2.
R2 (1 kΩ): between D1's anode and 3V3.

## Battery and regulator

J_BAT (JST-PH): pin 1 to the battery rail (VBAT), pin 2 to ground.
REG1 (TPS63001):
VIN, EN and VINA go to VBAT.
PS/SYNC, PGND and GND go to ground.
L1 and L2 go to the two ends of the inductor.
VOUT and FB go to 3V3.
L1 (2.2 µH): between REG1's two switch pins.
C1 (10 µF): VBAT to ground.
C2 (22 µF), C3 (10 µF): 3V3 to ground.

## Battery sensing

R7 (100 kΩ): VBAT to the sense node.
R8 (100 kΩ): sense node to ground.
C8 (100 nF): sense node to ground.
The sense node goes to U1 pin 9.

## Microcontroller and buttons

U1 (ESP32 module):
3V3 is on pin 3, and all the GND pads (including the large thermal pad) go to ground.
Pin 4 (IO0) goes to SW_BOOT and R6.
Pin 45 (EN) goes to SW_RST and R5.
Pin 9 is the battery sense node.
Pins 14, 15 and 16 go to SW1, SW2 and SW3.
Pins 23 and 24 are USB D− and D+.
Every other pin is unused.
R5, R6 (10 kΩ): pull-ups from EN and IO0 up to 3V3.
SW_RST: EN to ground. SW_BOOT: IO0 to ground.
C5, C6, C7 (100 nF, 100 nF, 10 µF): 3V3 to ground, U1 decoupling.
SW1, SW2, SW3: each switches its U1 pin to ground.
C9, C10, C11 (100 nF): each sits across its switch's U1 line to ground, for debounce.

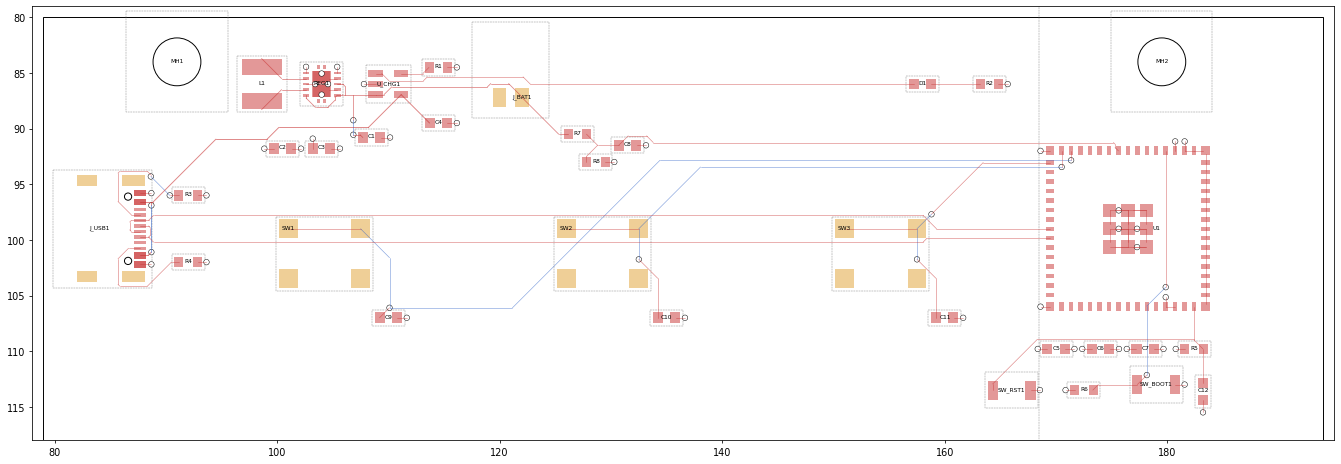
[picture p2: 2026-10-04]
electrical/mechanical_switch/RB_Switch_layout_preview.png

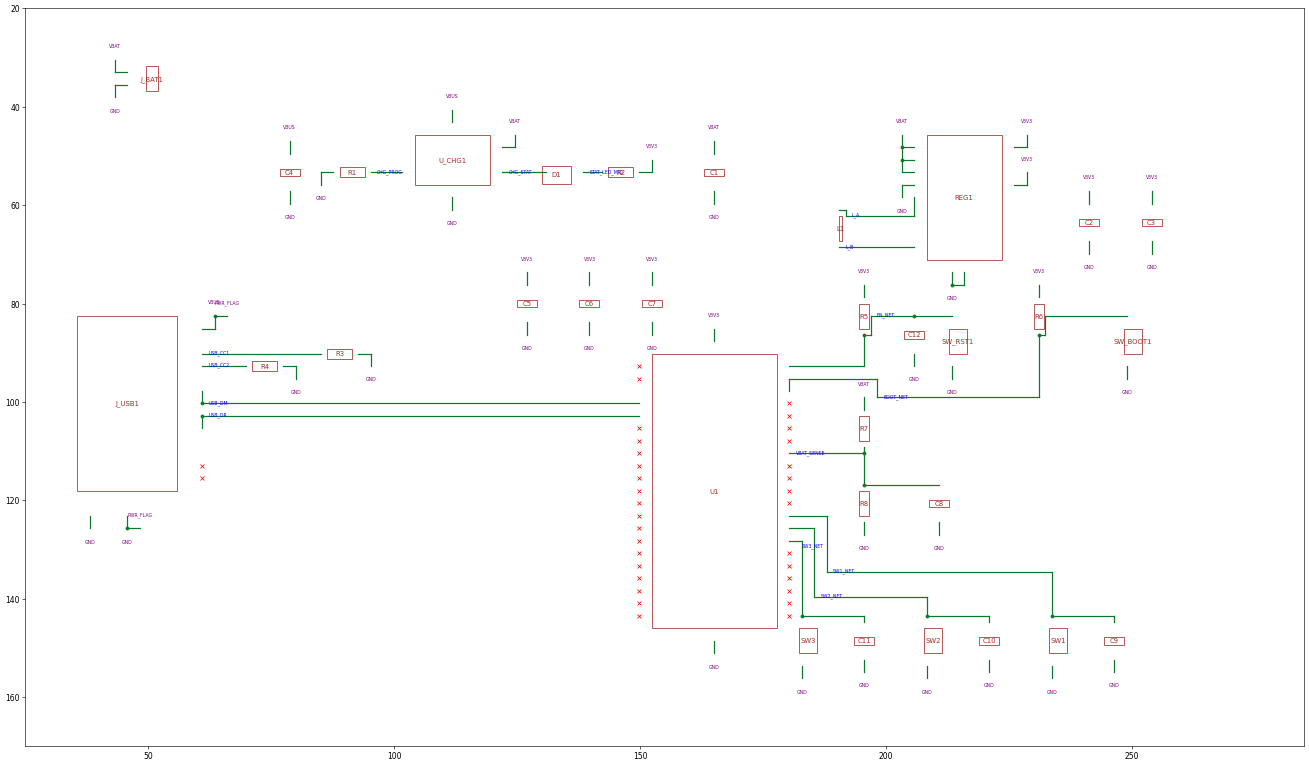
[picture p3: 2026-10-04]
electrical/mechanical_switch/RB_Switch_schematic_preview.png

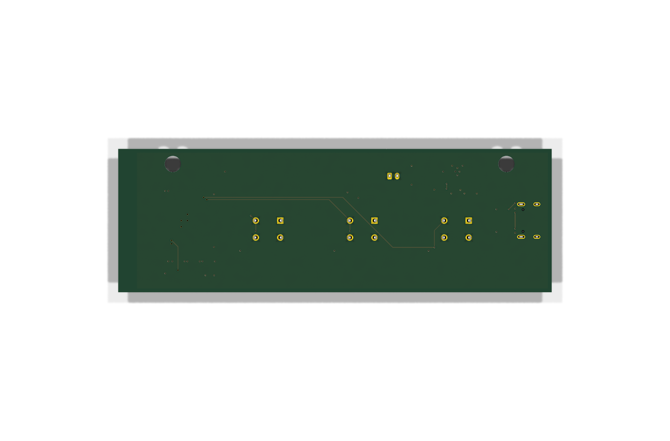
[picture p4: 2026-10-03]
electrical/mechanical_switch/diagrams/RB_Switch_BOTTOM.png

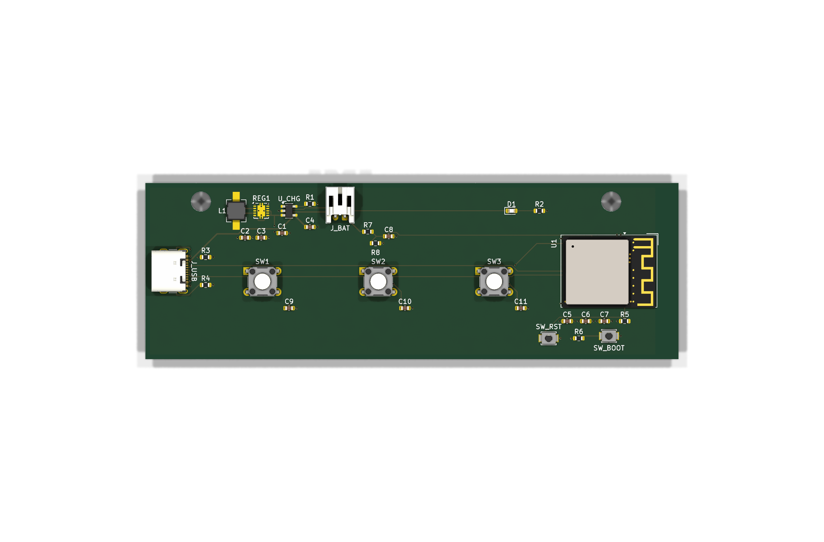
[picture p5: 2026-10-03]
electrical/mechanical_switch/diagrams/RB_Switch_3D.png

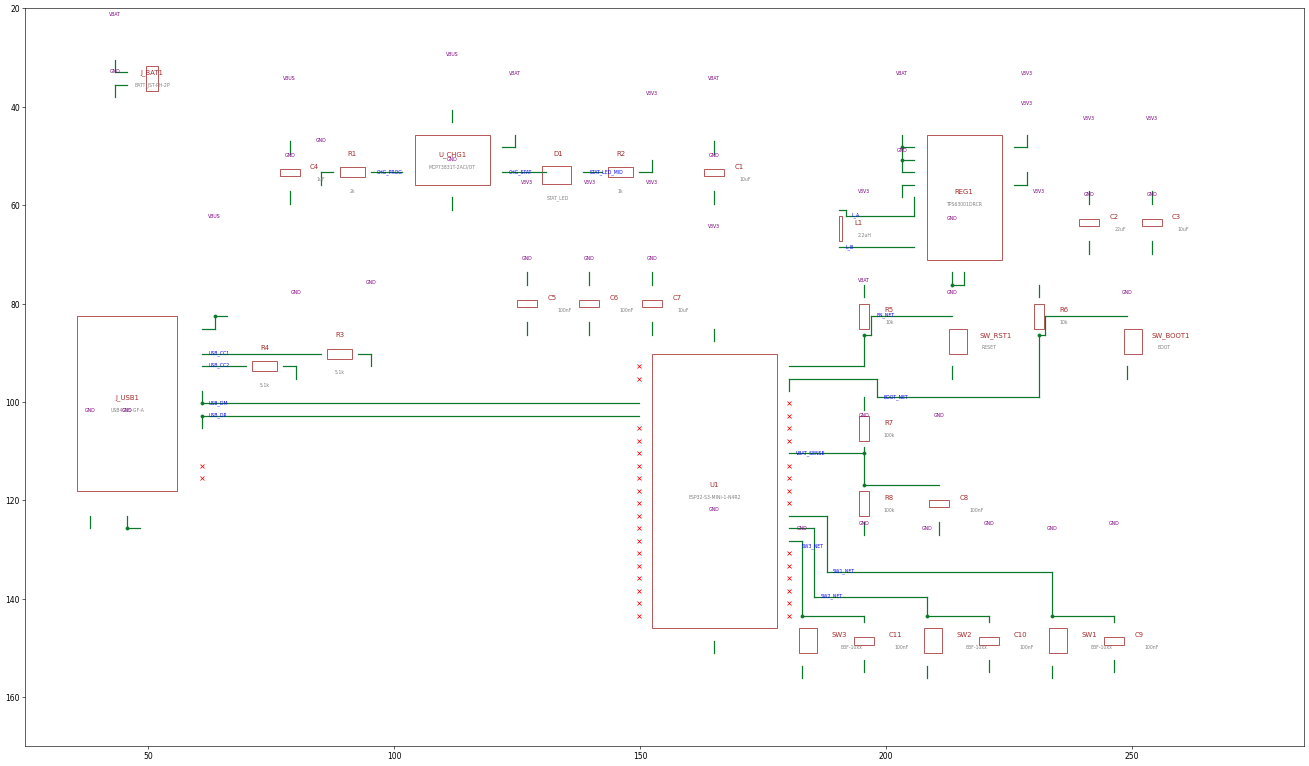
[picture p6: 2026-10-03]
electrical/mechanical_switch/diagrams/RB_Switch_schematic_preview.png

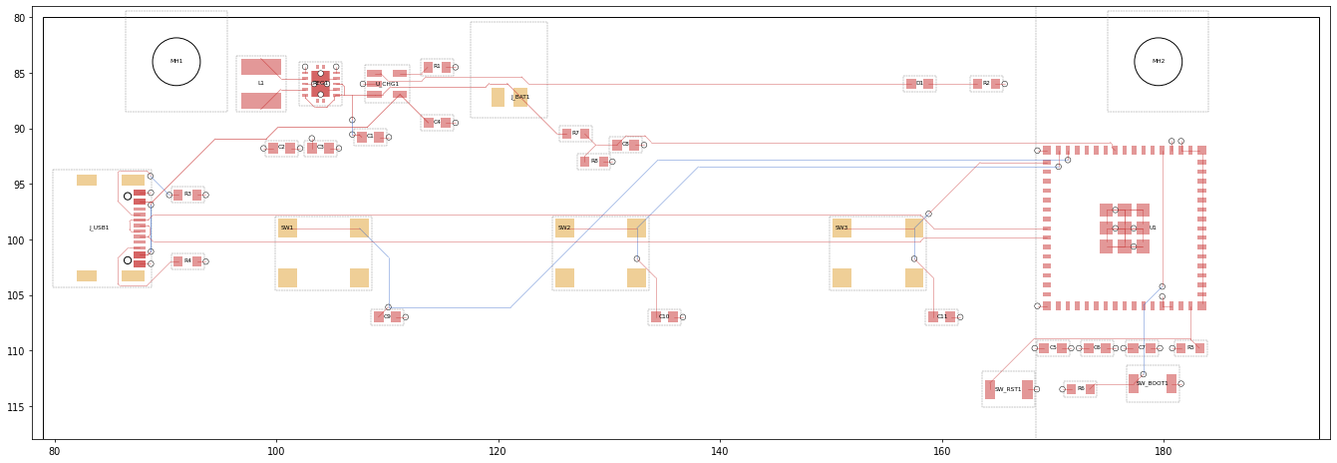
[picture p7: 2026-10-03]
electrical/mechanical_switch/diagrams/RB_Switch_layout_preview.png

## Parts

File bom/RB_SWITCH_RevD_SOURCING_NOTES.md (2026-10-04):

# RB_SWITCH RevD – sourcing notes (checked 2026-09-29; BOM/CPL notes updated 2026-10-03)

Stock figures come from search snapshots of Digi-Key, LCSC and JLCPCB part pages, some undated. They are **not live**. Re-check at order time, especially the parts marked ⚠.

## Part selection

| Ref | Part (MPN) | JLCPCB / LCSC # | Digi-Key P/N | Alternate / note |
|---|---|---|---|---|
| U1 | ESP32-S3-MINI-1-N4R2 | C3013941 (Ext.) | 1965-ESP32-S3-MINI-1-N4R2CT-ND | ⚠ LCSC stock flipped between 0 and ~2k in snapshots. Fallback: ESP32-S3-MINI-1-N8, **C2913206** (same footprint/pinout, 8 MB flash, no PSRAM). |
| REG1 | TPS63001DRCR | C28060 (~5.7k at JLC) | 296-19643-1-ND | TPS63001DRCT = C2070693 / 296-32517-1-ND. JLC flags it as needing an assembly fixture. |
| U_CHG1 | MCP73831T-2ACI/OT | C424093 | MCP73831T-2ACI/OTCT-ND (~43.9k) | Don't swap option codes (2DCI, 2ATI…) without checking datasheet thresholds. |
| J_USB1 | USB4105-GF-A | C3020560 | 2073-USB4105-GF-ACT-ND | ⚠ JLC stock thin/volatile (snapshot: 8; another source ~1.1k; LCSC retail 0). Fallback **USB4105-GF-A-120 = C5184243** (1.2 mm shell stakes vs 0.95 mm; sticks out ~0.2 mm under a 1.0 mm PCB). Both carry JLC's "high difficulty" $0.03/pc fee. |
| J_BAT1 | S2B-PH-K-S(LF)(SN) | C173752 (Ext., THT) | 455-1719-ND | S2B-PH-K(LF)(SN) = C265016 is also listed; confirm drawing before substituting. |
| L1 | SRN4018-2R2M | C913207 | SRN4018-2R2MCT-ND | 2.2 µH, Isat 3.0 A, 4×4 mm, 1.88 mm max height. See flag 1. |
| D1 | KT-0603R (red) | C2286 (Basic) | Würth 150060RS75000 = 732-4978-1-ND | Red/green/yellow only. See flag 3. |
| R1 2k | 0603WAF2001T5E | C22975 (Basic) | Yageo RC0603FR-072KL | |
| R2 1k | 0603WAF1001T5E | C21190 (Basic) | Yageo RC0603FR-071KL | |
| R3,R4 5.1k | 0603WAF5101T5E | C23186 (Basic) | Yageo RC0603FR-075K1L | |
| R5,R6 10k | 0603WAF1002T5E | C25804 (Basic) | Yageo RC0603FR-0710KL | |
| R7,R8 100k | 0603WAF1003T5E | C25803 (Basic) | Yageo RC0603FR-07100KL | |
| C1,C3,C7 10 µF | CL10A106KP8NNNC (10 V X5R) | C19702 (Basic) | 1276-1192-1-ND | |
| C2 22 µF | CL10A226MQ8NRNC (6.3 V X5R) | C59461 | 1276-1193-1-ND | JLC-verified alternate: CL10A226MQ8NRNE = **C159801** (Ext.). |
| C4, C12 1 µF | CL10A105KB8NNNC (50 V X5R) | C15849 (Basic) | 1276-1860-1-ND | C4 is the charger VBUS input cap. C12 (added 2026-10-03) is the EN-to-ground reset-delay cap. |
| C5,C6,C8–C11 100 nF | CC0603KRX7R9BB104 | C14663 (Basic) | Yageo (same MPN) | |
| SW_RST1, SW_BOOT1 | B3U-1000P | C231329 | SW1020CT-ND (~88k) | Alt JLC listing C271754; with-boss variant B3U-1000P-B = C231330 / SW1143CT-ND. |
| **SW1–SW3** | **B3F-1000** | **C93157** (Ext., THT) | **SW400-ND** (~27–40k) | ⚠ LCSC snapshot showed ~1.5k. Omron lists it "in production". |

Extended-part types on the JLC build: U1, REG1, U_CHG1, J_USB1, J_BAT1, L1, C2, SW_RST1/BOOT1 and SW1–3. Each type carries JLC's per-part loading fee.

## CPL changes vs. the templates

The CPL files were regenerated on 2026-10-03 from the current `RB_Switch.kicad_pcb`. All parts except U_CHG1, REG1, D1 and R2 moved, and U1 is now rotated 270° (it was 90°).

1. **Coordinates are relative to the board's top-left corner (X 79, Y 80 in KiCad), with Y negated.** This is the same convention as the earlier CPL. The gerbers run Y = 0 to −38, and the templates used KiCad's raw positive Y, which would mirror every part top-to-bottom.
2. **THT rows (SW1–3, J_BAT1) use the body centre**, not KiCad's pin-1 origin. JLC hand/wave-solders THT and does not use these rows, so delete them if the uploader complains.
3. **JLC rotations** keep the earlier corrections: U_CHG1 +270, SW_RST1/SW_BOOT1 +90, J_BAT1 +180 on top of KiCad's rotation.
4. **PCBWay CPL uses raw KiCad rotations**, except J_USB1, which keeps the 180° value from the earlier file.
5. **Verify orientation in the JLC/PCBWay preview** for U1, REG1 (VSON, pin 1), D1 (cathode = pad 1), J_USB1 and L1. No published correction covers them. In particular U1 and J_USB1 were re-rotated or re-derived and have not been checked against a fab preview.
6. **Re-export gerbers first.** The gerbers in `electrical/mechanical_switch/gerbers/` are from an earlier layout and will not match this CPL.

## Flags found while reading the design files

1. **L1 (resolved 2026-10-03).** The schematic and PCB now both use `L_Bourns-SRN4018`, and the BOMs list **SRN4018-2R2M**. The PCB land pattern matches the Bourns recommended layout (pads 1.5 × 3.6 mm, 4.55 mm overall). Height is 1.88 mm max for the 2R2M, well inside the enclosure's clearance.
2. **C2 22 µF at 6.3 V** loses much of its capacitance at 3.3 V DC bias. C3 and C7 add to the rail, but check the TPS63001 datasheet's minimum output capacitance.
3. **Status LED** is fed from 3V3 through R2 = 1k, about 1.3 mA with a red LED. A blue or white LED would barely light. Worth a bench check that it stays dark on battery power alone (unverified: current could leak through the charger's STAT pin when VBUS is absent).
4. **Battery pack** (BT1 in the generic BOM) is still "TBD". Verify JST polarity and protection circuit before first power-up.

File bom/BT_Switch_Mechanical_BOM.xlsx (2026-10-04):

Ref Des | Description | Manufacturer | Part Number | Package / Footprint | Qty | Notes
CORE / MCU
U1 | MCU module — WiFi/BLE SoC, 4MB flash, 2MB PSRAM | Espressif | ESP32-S3-MINI-1-N4R2 | SMD castellated module (RF_Module:ESP32-S2-MINI-1 land pattern) | 1 | PCB uses the RF_Module:ESP32-S2-MINI-1 footprint, the land pattern shared with the S3 module. The schematic symbol is the S3 part.
POWER — REGULATION & CHARGING
REG1 | Buck-boost regulator, fixed 3.3V out, 1.7A switch current | Texas Instruments | TPS63001DRCR | VSON-10 (Package_SON:Texas_DRC0010J) | 1 | Single-cell Li-ion buck-boost; handles ESP32-S3 BLE TX current peaks with margin.
U_CHG1 | Li-ion linear charge management IC, USB input | Microchip | MCP73831T-2ACI/OT | SOT-23-5 | 1 | ADDED vs. original BOM — battery + USB-C strongly implies charging; flagged as a scope addition.
L1 | Inductor, 2.2uH, shielded | Bourns | SRN4018-2R2M | SMD 4x4mm (Inductor_SMD:L_Bourns-SRN4018) | 1 | Buck-boost inductor (single inductor, L1/L2 pins of REG1).
D1 | Charge-status LED | Generic (e.g. Kingbright) | APT2012xx-series or equiv. | 0603 SMD | 1 | Lit while charging (STAT pin, open-drain).
C1 | Capacitor, 10uF, X5R, 10V | Generic | — | 0603 | 1 | REG1 input.
C2 | Capacitor, 22uF, X5R, 10V | Generic | — | 0603 (CL10A226MQ8NRNC, 6.3 V X5R) | 1 | REG1 output; 0603 22 uF X5R. Expect heavy DC-bias derating at 3.3 V.
C3 | Capacitor, 10uF, X5R, 10V | Generic | — | 0603 | 1 | 3V3 rail bulk decoupling.
C4, C12 | Capacitor, 1uF, X5R, 10V | Generic | — | 0603 | 2 | C4: charger VBUS input decoupling. C12: EN-to-GND, forms an RC reset delay with R5 (10 k x 1 uF).
R1 | Resistor, 2k, 1% | Generic | — | 0603 | 1 | Sets MCP73831 charge current to 500mA (I=1000V/R_PROG).
R2 | Resistor, 1k | Generic | — | 0603 | 1 | STAT LED current limit.
USB-C PORT
J_USB1 | USB-C receptacle, 16-pin, mid-mount, low profile | GCT | USB4105-GF-A | SMD 16-pin (Connector_USB:USB_C_Receptacle_GCT_USB4105-xx-A_16P_TopMnt_Horizontal) | 1 | D+/D- wired to ESP32-S3 native USB (no separate USB-UART bridge IC needed).
R3, R4 | Resistor, 5.1k, 1% | Generic | — | 0603 | 2 | CC1/CC2 pulldowns — configures port as a default 5V/500mA-3A USB-C sink.
BATTERY
J_BAT1 | Battery connector, JST-PH, 2-pin, side-entry | JST | S2B-PH-K-S | Connector_JST:JST_PH_S2B-PH-K_1x02_P2.00mm_Horizontal | 1
R7, R8 | Resistor, 100k, 1% | Generic | — | 0603 | 2 | Battery voltage sense divider (÷2) for ADC monitoring on GPIO5.
C8 | Capacitor, 100nF | Generic | — | 0603 | 1 | ADC sense filter.
BT1 | Li-Po battery pack, 3.7V nominal, ~3000mAh, JST-PH 2-pin | MakerFocus (or equiv.) | TBD — exact purchased SKU | 65 x 36 x 10mm envelope (per COMPONENT_DIMENSIONS) | 1 | OPEN ITEM: confirm exact purchased part — connector polarity/pinout and onboard protection circuit both need verifying against the real pack before first power-up.
MCU SUPPORT
C5, C6 | Capacitor, 100nF | Generic | — | 0603 | 2 | ESP32-S3 3V3 decoupling.
C7 | Capacitor, 10uF | Generic | — | 0603 | 1 | ESP32-S3 3V3 bulk decoupling.
R5 | Resistor, 10k | Generic | — | 0603 | 1 | EN pull-up.
R6 | Resistor, 10k | Generic | — | 0603 | 1 | GPIO0 (BOOT) pull-up.
SW_RST1 | Tactile switch, low-profile SMD | Omron | B3U-1000P | SMD (Button_Switch_SMD:SW_SPST_B3U-1000P) | 1 | Manual reset.
SW_BOOT1 | Tactile switch, low-profile SMD | Omron | B3U-1000P | SMD (Button_Switch_SMD:SW_SPST_B3U-1000P) | 1 | Manual download-mode entry.
STUDENT-FACING SWITCHES (the click)
SW1, SW2, SW3 | Tactile switch, THT, metal-dome click, 6x6mm | Omron | B3F-1000 (or B3F-4050 for higher actuation force) | THT (Button_Switch_THT:SW_TH_Tactile_Omron_B3F-100x) | 3 | OPEN ITEM: confirm exact force-grade suffix against target students' motor range — B3F-1000 ≈100gf, B3F-4050 ≈260gf. Real click, real audible+tactile feedback.
C9, C10, C11 | Capacitor, 100nF | Generic | — | 0603 | 3 | Debounce/ESD filtering on each switch input.
PCB & FASTENERS
PCB1 | 4-layer PCB, 115 x 38mm, 1.0mm thick, ENIG or HASL | Any capable fab (e.g. JLCPCB) | Per Gerbers in electrical/mechanical_switch/gerbers/ | 0.15mm/0.15mm trace/space | 1
MH1, MH2 | M4 self-tapping screw, ~8mm length | Generic (McMaster, etc.) | M4 x 8mm, pan or button head, plastic self-tap thread | — | 2 | Registers PCB to enclosure at the front-edge mounting holes; also the primary case fastening at the front.
ENCLOSURE (3D printed)
ENC-BASE | Enclosure base, 3D printed | In-house print | BT_Switch_Mechanical_base_RevD2.stl | PETG recommended (impact resistance for classroom use) | 1
ENC-LID | Enclosure lid, 3D printed | In-house print | BT_Switch_Mechanical_lid_RevD2.stl | PETG | 1
ENC-BAR | Button cap / captive bar, 3D printed | In-house print | BT_Switch_Mechanical_bar_RevD2.stl | PETG (or a more flexible filament like TPU for a softer button feel) | 3 | One per switch position.
Highlighted rows = open item, needs confirmation before ordering/printing.

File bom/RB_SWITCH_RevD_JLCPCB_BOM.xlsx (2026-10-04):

Comment | Designator | Footprint | JLCPCB Part #（optional）
ESP32-S3-MINI-1-N4R2 | U1 | ESP32-S2-MINI-1 | C3013941
TPS63001DRCR | REG1 | Texas_DRC0010J | C28060
MCP73831T-2ACI/OT | U_CHG1 | SOT-23-5 | C424093
USB4105-GF-A | J_USB1 | USB_C_Receptacle_GCT_USB4105-xx-A_16P_TopMnt_Horizontal | C3020560
BATT_JST-PH-2P | J_BAT1 | JST_PH_S2B-PH-K_1x02_P2.00mm_Horizontal | C173752
2.2uH | L1 | L_Bourns-SRN4018 | C913207
STAT_LED | D1 | LED_0603_1608Metric | C2286
2k | R1 | R_0603_1608Metric | C22975
1k | R2 | R_0603_1608Metric | C21190
5.1k | R3,R4 | R_0603_1608Metric | C23186
10k | R5,R6 | R_0603_1608Metric | C25804
100k | R7,R8 | R_0603_1608Metric | C25803
10uF | C1,C3,C7 | C_0603_1608Metric | C19702
22uF | C2 | C_0603_1608Metric | C59461
1uF | C4,C12 | C_0603_1608Metric | C15849
100nF | C5,C6,C8,C9,C10,C11 | C_0603_1608Metric | C14663
RESET | SW_RST1 | SW_SPST_B3U-1000P | C231329
BOOT | SW_BOOT1 | SW_SPST_B3U-1000P | C231329
B3F-1000 | SW1,SW2,SW3 | SW_TH_Tactile_Omron_B3F-100x | C93157

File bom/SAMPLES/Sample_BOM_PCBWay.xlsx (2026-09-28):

 |  |  | xxxx xxxx xxxxx xxPCS BOM (Sample Bill of Materials)
Item # | *Designator | *Qty | Manufacturer | *Mfg Part # | Description / Value | *Package/Footprint | Type | Your Instructions / Notes
1 | U1 | 1 | Linear | LTC3780EG#PBF | IC BUCK-BOOST CONV 24-SSOP | 24-SSOP | SMD
2 | U2,U4 | 2 | Fairchild | LM2904M | IC OPAMP DUAL -40-85 C 8-SOIC | 8-SOIC | DNS
3 | U3 | 1 | ON | LM317MBDTG | LM317M IC REG VOLT ADJ 500MA DPAK | DPAK | SMD
4 | U5 | 1 | Microchip | PIC16F690-I/SS | IC PIC MCU FLASH 4KX14 20SSOP | 20SSOP | SMD
5 | Q1 | 1 | Diodes Inc | GBJ10005-F | RECT BRIDGE GPP 50V 10A GBJ | GBJ | SMD
6 | R14,R18 | 2 | Panasonic | ERJ-6ENF4701V | RES 4.70K OHM 1/8W 1% 0805 SMD | 0805 | SMD
7 | R15 | 1 | Susumu | RL3720WT-R022-F | RES .022 OHM 1W 1% 0815 SMD | 0815 | SMD
8 | R16, R31 | 2 | Panasonic | ERJ-6ENF4702V | RES 47.0K OHM 1/8W 1% 0805 SMD | 0805 | SMD
9 | C5 | 1 | Murata | GRM21BR71C225KA12L | CAP CER 2.2UF 16V X7R 0805 | 0805 | SMD
10 | C7 | 1 | Murata | GRM21BR71C475KA73L | CAP CER 4.7UF 16V X7R 0805 | 0805 | DNS
11 | C8,C22 | 2 | Muruta | GRM21BR71C105KA01L | CAP CER 1.0UF 16V 10% X7R 0805 | 0805 | SMD
12 | CN6 | 1 | Molex | 538-53398-0671 | 1.25mm Connectors VERTICAL HDR SMT 6P | SMT 6P | SMD
13 | L1,L2 | 2 | Coiltronics | DR127-150-R | INDUCTOR SHIELD PWR 15UH SMD | SMD | SMD
14 | L3 | 1 | TDK | ACM1211-102-2PL-TL | CHOKE COMM MODE 1000 OHM 6A SM | SMD | SMD
15 | CN3,CN4 | 2 | Molex | 53047-0510 | CONN HEADER 5POS 1.25MM VERT TIN | 5POS | thru-hole
Need a quick and accurante quote? Need an efficient production? Please read SMT Ordering Necessary Files & Info in 1 minute. Thank you very much! (https://www.pcbway.com/smt_ordering_guide.html)
Click for Instructions on How to Create a BOM (https://www.pcbway.com/blog/PCB_Assembly/How_to_Build_a_BOM__Bill_Of_Materials_.html)

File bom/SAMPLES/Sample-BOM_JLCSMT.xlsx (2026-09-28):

Comment | Designator | Footprint | JLCPCB Part #（optional）
100uF | C1 | CAP-SMD_L3.5-W2.8 | C16133
15K | R5,R6 | R0603 | C22809
DC-005-20A_C136744 | DC1 | DC-IN-TH_DC-005-20A | C136744
Header-Female-2.54_1x8 | P2,P3 | HDR-TH_8P-P2.54-V | C27438
K2-1102DP-C4SW-04 | SW1 | KEY-TH_4P-L6.0-W6.0-P4.50-LS6.5 | C110153
ATMEGA328P-PU | U1 | DIP-28_L34.6-W7.3-P2.54-LS10.2-BL | C33901
670688000 | USB1 | USB-B-TH_67068-8000 | C114097

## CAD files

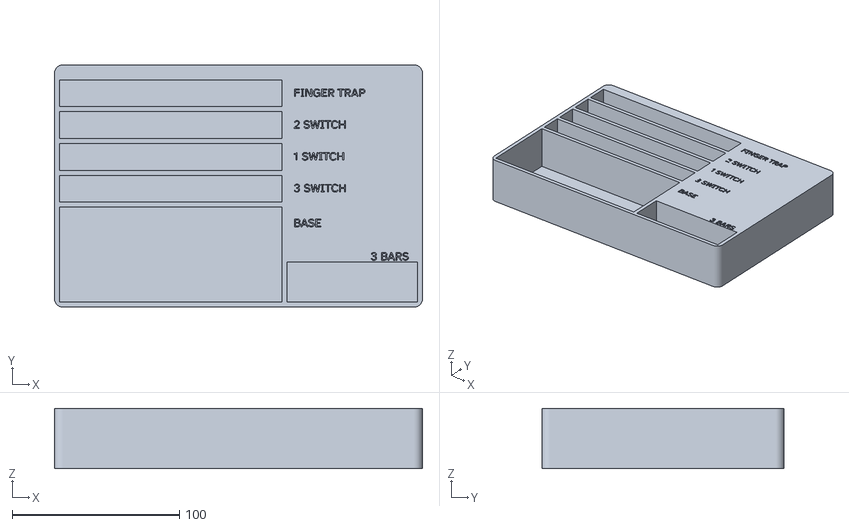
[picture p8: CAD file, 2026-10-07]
mechanical/assistive_switch_storage_box.stl
220.0 x 144.8 x 36.0

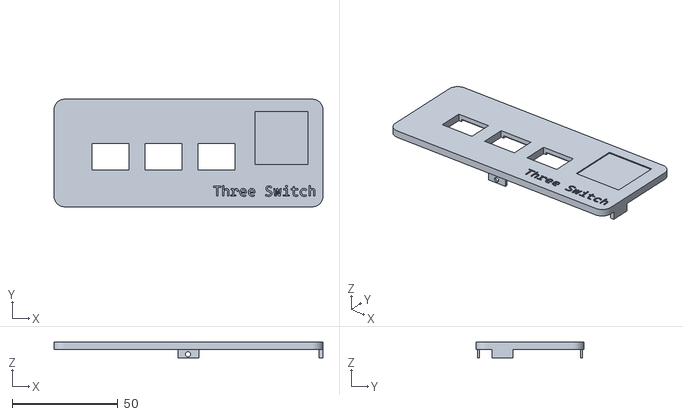
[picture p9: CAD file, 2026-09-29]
mechanical/Exported_20260929/enclosure_lid.stl
127.0 x 50.8 x 7.50

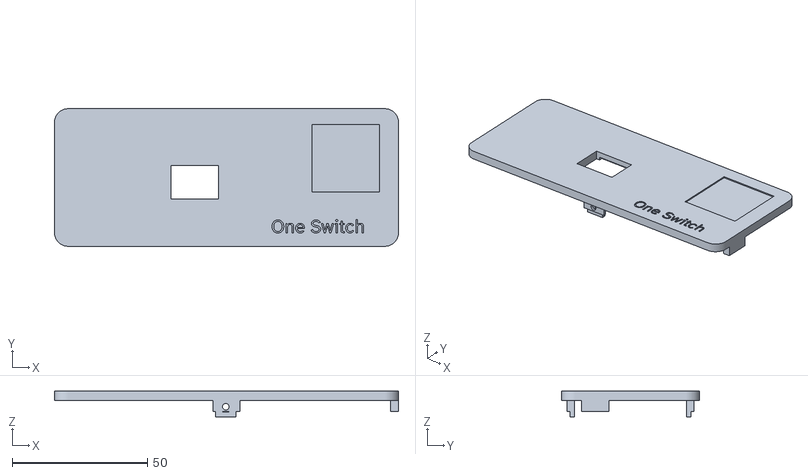
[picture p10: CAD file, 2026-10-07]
mechanical/enclosure_lid_oneswitch.stl
127.0 x 50.8 x 9.50

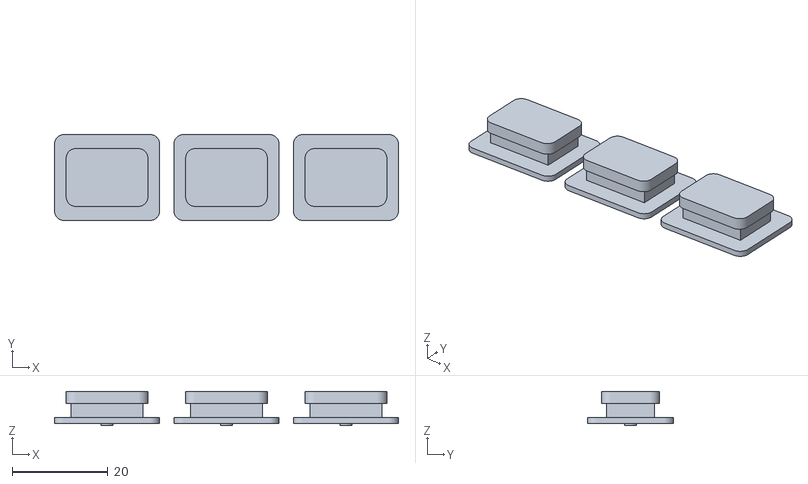
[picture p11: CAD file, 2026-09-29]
mechanical/Exported_20260929/enclosure_bar.stl
72.0 x 18.0 x 7.15

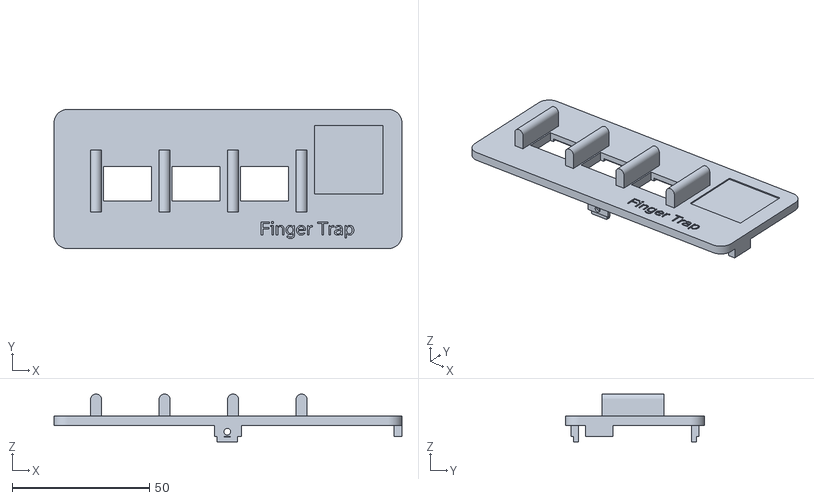
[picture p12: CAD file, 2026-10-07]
mechanical/enclosure_lid_fingertrap.stl
127.0 x 50.8 x 17.5

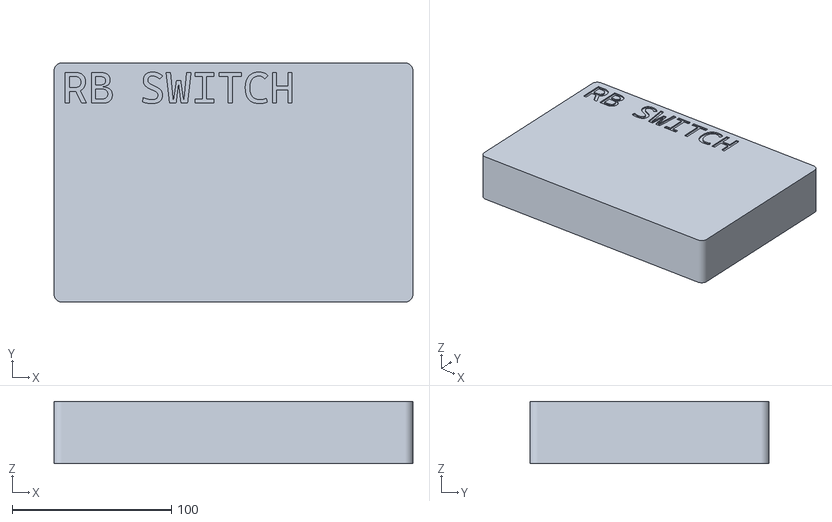
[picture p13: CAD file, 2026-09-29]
mechanical/Exported_20260929/assistive_switch_storage_box_lid.stl
225.5 x 150.3 x 39.0

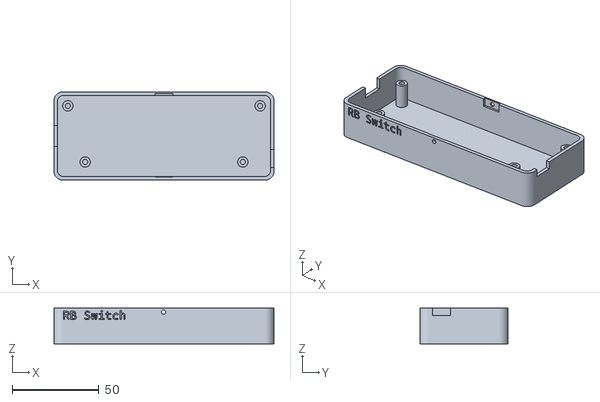
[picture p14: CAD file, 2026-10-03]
mechanical/enclosure_base.stl
127.0 x 50.8 x 20.5

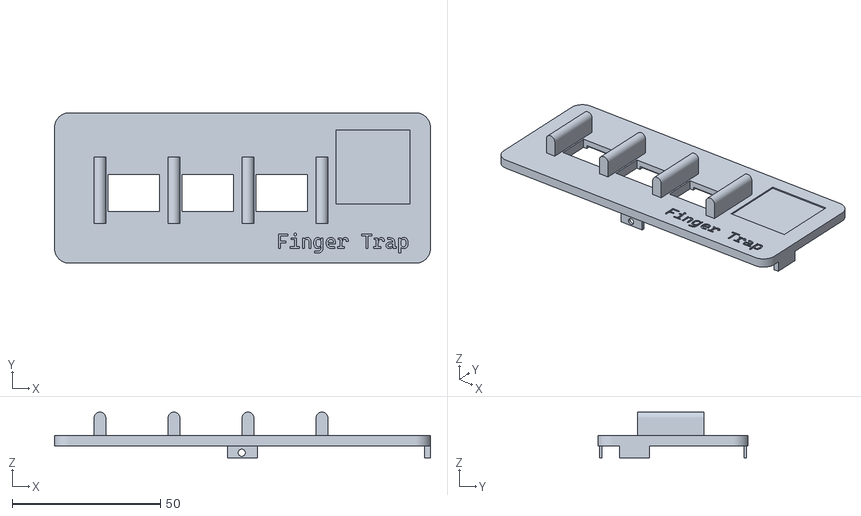
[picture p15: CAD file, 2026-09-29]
mechanical/Exported_20260929/enclosure_lid_fingertrap.stl
127.0 x 50.8 x 15.5

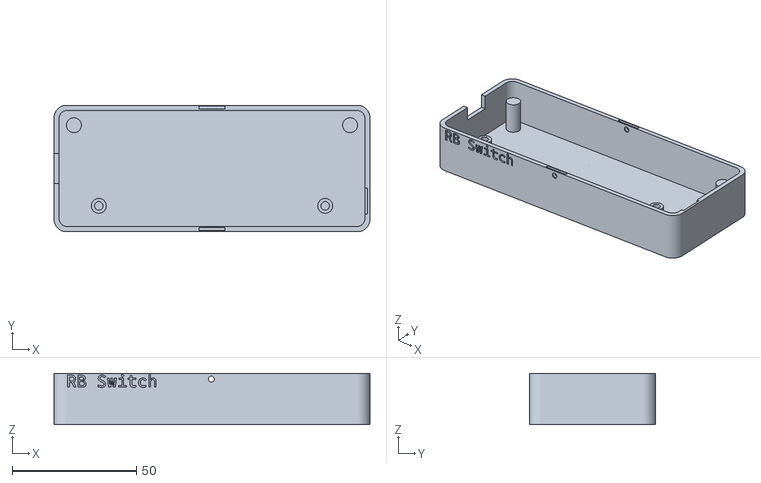
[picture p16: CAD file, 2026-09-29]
mechanical/Exported_20260929/enclosure_base.stl
127.0 x 50.8 x 20.5

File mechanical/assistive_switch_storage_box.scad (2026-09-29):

/*
 * RB Switch - Parts Storage Box
 *
 * Separate organizer for the assistive-switch enclosure parts.
 *
 * Storage layout:
 *   1. Main bay: one base() with lid_fingertrap() fitted on top.
 *      The bay height is sized from the maximum height of that assembly.
 *   2. Bar bay: room for 3 spare bar() parts.
 *   3. Four individual lid bays: lid(), lid_oneswitch(), lid_twoswitch(),
 *      and lid_fingertrap().
 *
 * This file intentionally does not modify the enclosure geometry.  The
 * dimensions below are derived from the supplied enclosure modules.
 */

$fn = 96;

// ---------------------------------------------------------------------
// Source enclosure dimensions
// ---------------------------------------------------------------------
L = 127;
W = 50.8;
H = 24.0;
LID_T = 3.5;

// Button geometry: the flange is the largest XY feature of bar().
BAR_L = 20;
BAR_W = 16;
BAR_H = 2.5;
FLANGE_L = 22;
FLANGE_W = 18;
FLANGE_T = 1.2;

// Finger-trap lid geometry.
DIVIDER_H = 8;

// ---------------------------------------------------------------------
// Storage clearances
// ---------------------------------------------------------------------
CLEAR_X = 3.0;       // clearance around 127 mm enclosure/lid length
CLEAR_Y = 3.0;       // clearance around 50.8 mm enclosure/lid width
WALL = 3.0;          // organizer wall/divider thickness
BOTTOM = 3.0;        // organizer floor thickness
TOP_CLEAR = 4.0;     // clearance above tallest stored assembly
LID_SLOT = 16.0;      // each lid gets its own 5 mm slot
BAR_CLEAR = 3.0;     // clearance around spare bars

// ---------------------------------------------------------------------
// Derived storage dimensions
// ---------------------------------------------------------------------
// Base() physical height is H-LID_T = 20.5 mm.
// Lid_fingertrap() is 3.5 mm thick with an 8 mm divider above it.
// Therefore the maximum stored assembly height is 20.5+3.5+8 = 32 mm.
BASE_ASSEMBLY_H = (H - LID_T) + LID_T + DIVIDER_H;

MAIN_X = L + 2*CLEAR_X;
MAIN_Y = W + 2*CLEAR_Y;

// Three bars are stored side-by-side in their own compartment.
// 22 x 18 is used because the flange is the largest bar footprint.
BAR_PITCH_X = FLANGE_L + BAR_CLEAR;
BAR_BAY_X = 3*FLANGE_L + 4*BAR_CLEAR;
BAR_BAY_Y = FLANGE_W + 2*BAR_CLEAR;

// Four lids are stored in four independent vertical slots.
LID_BAY_X = L + 2*CLEAR_X;
LID_BAY_Y = LID_SLOT;
LID_RACK_Y = 4*LID_SLOT + 5*WALL;

// Overall organizer arrangement:
//   [ MAIN BASE BAY ][ BAR BAY ]
//   [       4 INDIVIDUAL LID SLOTS       ]
OUTER_X = max(MAIN_X + WALL + BAR_BAY_X + 2*WALL, LID_BAY_X + 2*WALL);
OUTER_Y = MAIN_Y + WALL + LID_RACK_Y + 2*WALL;
OUTER_Z = BASE_ASSEMBLY_H + TOP_CLEAR;

// ---------------------------------------------------------------------
// Helpers
// ---------------------------------------------------------------------
module rounded_box(x,y,z,r=4) {
    hull() {
        translate([r,r,0]) cylinder(r=r,h=z);
        translate([x-r,r,0]) cylinder(r=r,h=z);
        translate([r,y-r,0]) cylinder(r=r,h=z);
        translate([x-r,y-r,0]) cylinder(r=r,h=z);
    }
}

// A compartment represented as a solid divider footprint.
module divider(x,y,sx,sy,h=OUTER_Z) {
    translate([x,y,0]) cube([sx,sy,h]);
}

// ---------------------------------------------------------------------
// Organizer body
// ---------------------------------------------------------------------
module storage_box() {
    difference() {
        // Solid outer shell.
        rounded_box(OUTER_X, OUTER_Y, OUTER_Z, 5);

        // Main base + finger-trap assembly bay.
        translate([WALL, WALL, BOTTOM])
            cube([MAIN_X, MAIN_Y, OUTER_Z-BOTTOM+0.1]);

        // Three-bar bay.
        translate([WALL + MAIN_X + WALL, WALL, BOTTOM])
            cube([BAR_BAY_X, BAR_BAY_Y, OUTER_Z-BOTTOM+0.1]);

        // Four individual lid slots.
        // They run the full lid length, giving each lid its own location.
        for (i=[0:3]) {
            y0 = WALL + MAIN_Y + WALL + i*(LID_SLOT+WALL);
            translate([WALL, y0, BOTTOM])
                cube([LID_BAY_X, LID_SLOT, OUTER_Z-BOTTOM+0.1]);
        }
    

    // Raised labels for the storage areas.
    // Main bay label
    translate([WALL+140, WALL+45, OUTER_Z-1.2])
        linear_extrude(height=1.2)
            text("BASE", size=5, font="Atkinson Hyperlegible Next");

    // Bar bay label
    translate([WALL+MAIN_X+WALL+50, WALL+25, OUTER_Z-1.2])
        linear_extrude(height=1.2)
            text("3 BARS", size=5, font="Atkinson Hyperlegible Next");

    // Individual lid labels on the rack divider areas.
    lid_names = ["3 SWITCH", "1 SWITCH", "2 SWITCH", "FINGER TRAP"];
    for (i=[0:3]) {
        y0 = WALL + MAIN_Y + WALL + i*(LID_SLOT+WALL);
        translate([WALL+140, y0+6, OUTER_Z-1.2])
            linear_extrude(height=1.2)
                text(lid_names[i], size=5, font="Atkinson Hyperlegible Next");
    }
    }
}

module lid_for_storage_box() {
    // -------------------------------------------------------------
    // Lid fit parameters
    // -------------------------------------------------------------
    LID_CLEAR_XY = 0.75;   // clearance per side; 2 mm total
    LID_CLEAR_Z  = 1.0;   // clearance above storage box
    LID_WALL     = 2.0;   // lid wall thickness
    LID_BOTTOM   = 2.0;   // closed end / top thickness
    LID_RADIUS   = 5.0;

    // -------------------------------------------------------------
    // Outer lid dimensions
    // -------------------------------------------------------------
    // The lid is slightly larger than the storage box in XY.
    LID_OUTER_X = OUTER_X + 2*LID_CLEAR_XY + 2*LID_WALL;
    LID_OUTER_Y = OUTER_Y + 2*LID_CLEAR_XY + 2*LID_WALL;

    // Internal cavity is large enough to slip over the entire box.
    LID_INNER_X = OUTER_X + 2*LID_CLEAR_XY;
    LID_INNER_Y = OUTER_Y + 2*LID_CLEAR_XY;

    // The cavity needs to extend 1 mm beyond the top of the box.
    LID_INNER_Z = OUTER_Z + LID_CLEAR_Z;

    // Overall lid height = cavity depth + top thickness.
    LID_OUTER_Z = LID_INNER_Z + LID_BOTTOM;

    difference() {
        // Solid lid
            rounded_box(
                LID_OUTER_X,
                LID_OUTER_Y,
                LID_OUTER_Z,
                LID_RADIUS
            );

        // Internal cavity.
        //
        // Starting at z=0 means the bottom of the lid is open.
        // The cavity extends 1 mm above the storage box, providing
        // vertical clearance instead of colliding with its top.
        translate([
            LID_WALL,
            LID_WALL,
            -0.01
        ])
                 rounded_box(
                    LID_INNER_X,
                    LID_INNER_Y,
                    LID_INNER_Z + 0.01,
                    LID_RADIUS
                );
        translate([5,125,LID_OUTER_Z+LID_CLEAR_Z-2])linear_extrude(height=1.2)
                text("RB SWITCH", size=20, font="Atkinson Hyperlegible Next");
    }
}

// ---------------------------------------------------------------------
// Optional storage contents for visual verification
// ---------------------------------------------------------------------
// These are deliberately simple envelope representations.  The actual
// enclosure modules can be brought into a separate scene if desired.

module stored_bar_envelope() {
    rounded_box(FLANGE_L, FLANGE_W, FLANGE_T, 2);
}

module stored_lid_envelope() {
    rounded_box(L, W, LID_T, 5);
}

// Maximum-height envelope for base() + lid_fingertrap().
module stored_base_fingertrap_envelope() {
    rounded_box(L, W, BASE_ASSEMBLY_H, 5);
}

// ---------------------------------------------------------------------
// Main output
// ---------------------------------------------------------------------
translate([0,155,0])storage_box();
//lid_for_storage_box();

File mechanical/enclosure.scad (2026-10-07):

/*
 * Licensed under the Apache License, Version 2.0 (the "License");
 * you may not use this file except in compliance with the License.
 * You may obtain a copy of the License at
 *
 *     http://www.apache.org/licenses/LICENSE-2.0
 *
 * Unless required by applicable law or agreed to in writing, software
 * distributed under the License is distributed on an "AS IS" BASIS,
 * WITHOUT WARRANTIES OR CONDITIONS OF ANY KIND, either express or implied.
 * See the License for the specific language governing permissions and
 * limitations under the License.
 */

/*
 * RB Switch Enclosure - Mechanical Switch Variant
 *
 * OpenSCAD design for a 3D-printable enclosure for a Bluetooth switch device with mechanical buttons.
 *
 * Features:
 * - Secure lid with three internal retention tabs
 * - Two long-side tabs
 * - One short-side press-fit tab
 * - M2/M4 screw/nut geometry retained
 * - Button bar openings for tactile switches
 * - USB-C charging access with funnel guide
 * - Battery compartment
 * - PCB mounting standoffs
 *
 * IMPORTANT:
 * The lid retention tabs are positioned against the INSIDE of the
 * base walls. The corresponding slots in the base are cut through
 * the wall thickness so the lid tabs can enter the slots when the
 * lid is installed.
 *
 * LONG-SIDE TAB SCREW HOLES:
 * The long-side lid tabs now have a horizontal M2 clearance hole on
 * the same axis as the cylinder cutout in the base walls, so a single
 * M2 screw can pass through the wall and the installed tab. The axis
 * is defined once (TAB_SCREW_*) and shared by base and lid so the
 * holes always line up.
 *
 * LID NUT TRAPS:
 * Each long-side tab carries a hex nut trap on its cavity side,
 * fused into the lid underside. Press an M2 nut into the trap (with
 * the lid off), then tighten the M2 screw from outside the case to
 * clamp the wall and tab together.
 *
 * SHORT-SIDE LAYOUT (updated):
 * The USB-C cutout is now on the LEFT short side (x = 0).
 * The short-side press-fit tab and its base slot are now on the
 * RIGHT short side (x = L), opposite the USB-C cutout.
 */

// ---------------------------------------------------------------------
// VARIABLES
// ---------------------------------------------------------------------
//smooth round edges
$fn = 128;

// M2 screw radius
M2 = 1;

// Box Dimensions
L = 127;
W = 50.8;
H = 24.0;
WALL = 2.0;
BOTTOM = 1.8;
LID_T = 3.5;

// PCB Dimensions
PCB_L = 115;
PCB_W = 38;
PCB_T = 1.0;

// LiPo Battery Dimensions
BAT_L = 68;
BAT_W = 38;
BAT_H = 10.0;
BAT_CLR = 0.8;

// Push Button Dimensions
// Sized to fit the PCB's actual 25mm switch pitch with a 3mm visual gap
// between adjacent button caps.
BAR_L = 20;
BAR_W = 16;
BAR_H = 2.5;

OPEN_L = 17.5;
OPEN_W = 12.5;

STEM_L = 15;
STEM_W = 10;
STEM_H = 3.0;

FLANGE_L = 22;
FLANGE_W = 18;
FLANGE_T = 1.2;

// Top cap is the only portion that passes through the lid opening.
// 0.2 mm clearance is provided on each side.
TOP_L = OPEN_L - 0.4;
TOP_W = OPEN_W - 0.4;
TOP_R = 2.0;

TRAVEL = 0.8;

// ---------------------------------------------------------------------
// LID RETENTION TABS
// ---------------------------------------------------------------------

// The tabs are deliberately positioned on the INSIDE of the base walls.

// Long-side tabs:
//
//   y = WALL
//   y = W - WALL - TAB_W_LONG
//
// This places each tab immediately against the inside face of its
// corresponding 2 mm wall.

// The short/right-side tab is positioned on the inside face of the
// right-hand wall, opposite the USB-C cutout (which is now on the
// left-hand wall).

TAB_L = 10;
TAB_W_LONG = 1.0;
TAB_HEIGHT = 4.0;

// X position of the long-side tabs
LONG_TAB_X = L / 2;

// Y positions of the long-side tabs.
// These are now INSIDE the enclosure walls.
LONG_TAB_Y = [
    WALL,
    W - WALL - TAB_W_LONG
];

// Slot parameters for long-side tabs
SLOT_L = TAB_L + 0.5;
SLOT_W_LONG = TAB_W_LONG + 0.2;
SLOT_H = TAB_HEIGHT + 0.5;

// Vertical tab on right side, opposite USB-C
SHORT_TAB_X = L - WALL;
SHORT_TAB_Y = 12.4;

// Slot parameters for vertical tab
// 0.2 mm vertical clearance provides a snug printable fit.
SHORT_SLOT_W = 1.0;
SHORT_SLOT_L = TAB_L + 0.5;
SHORT_SLOT_H = TAB_HEIGHT + 0.2;

// ---------------------------------------------------------------------
// M2 SCREW HOLE THROUGH LONG-SIDE TABS
// ---------------------------------------------------------------------

// Axis of the horizontal M2 clearance hole that passes through the
// long-side base walls and the installed long-side lid tabs.
// These values are shared by the base cutout and the lid tab cutout
// so the two holes are always concentric.

// X position of the screw axis
TAB_SCREW_X = LONG_TAB_X - SLOT_L / 2 + 5;

// Z position of the screw axis in BASE coordinates
TAB_SCREW_Z = H - LID_T - SLOT_H + 2.25;

// Z position of the screw axis in LID-LOCAL coordinates
// (the lid is placed at z = H - LID_T in the assembly)
TAB_SCREW_Z_LID = TAB_SCREW_Z - (H - LID_T);

// 2.4 mm clearance hole for an M2 screw
TAB_SCREW_R = M2 + 0.2;

// ---------------------------------------------------------------------
// M2 NUT TRAP (LID SIDE)
// ---------------------------------------------------------------------

// Standard M2 hex nut.
M2_NUT_AF = 4.0; // width across flats
M2_NUT_T = 1.6;  // thickness

// Hex pocket: 0.1 mm press fit so the nut stays seated in the lid
// until the screw engages. The pocket opens toward the enclosure
// cavity; the tab's inner face is the nut seat.
NUT_POCKET_AF = M2_NUT_AF - 0.1;
NUT_POCKET_R = NUT_POCKET_AF / sqrt(3); // hex circumradius
NUT_POCKET_T = M2_NUT_T + 0.15;         // slight extra depth

// Material around the hex pocket
NUT_WALL = 1.5;

// Lid underside overlap so tab-side parts fuse with the lid body
TAB_JOIN = 0.3;

// ---------------------------------------------------------------------
// PCB REGISTRATION DATUM
// ---------------------------------------------------------------------

// PCB centered in the case interior.
// 123 x 46.8 mm clear.
//
// WALL + half the slack.
PCB_OFFSET = [
    WALL + ((L - 2 * WALL) - PCB_L) / 2,
    WALL + ((W - 2 * WALL) - PCB_W) / 2
]; // = [6, 6.4]

// Real PCB-local coordinates (from build_mech_pcb.py)
// Do not hand-edit without updating the PCB to match.
PCB_SWITCH_XY = [
    [22, 19],
    [47, 19],
    [72, 19]
]; // SW1, SW2, SW3

PCB_M4_XY = [
    [12, 4],
    [103, 4]
]; // MH1, MH2 (front edge)

PCB_USB_XY = [5, 19]; // J_USB origin (rot=180, nose -> PCB x=0)

// Font for all Text CutOuts
FONT = "Atkinson Hyperlegible Next";

function to_case(p) = [
    p[0] + PCB_OFFSET[0],
    p[1] + PCB_OFFSET[1]
];

CASE_SWITCH_XY = [
    for (p = PCB_SWITCH_XY)
        to_case(p)
];

CASE_M4_XY = [
    for (p = PCB_M4_XY)
        to_case(p)
];

CASE_USB_XY = to_case(PCB_USB_XY);

BAR_X = [
    for (s = CASE_SWITCH_XY)
        s[0] - BAR_L / 2
];

BAR_Y = CASE_SWITCH_XY[0][1] - BAR_W / 2;

// ---------------------------------------------------------------------
// Z DIMENSIONS
// ---------------------------------------------------------------------

PCB_TOP_Z =
    BOTTOM +
    BAT_H +
    1.2 +
    2.0 +
    PCB_T; // = 16.0

LID_Z = H - LID_T;

SWITCH_H = 4.3; // B3F-1000
SWITCH_SAFE_TRAVEL = 0.5; // B3F-1000

CLEARANCE_AVAILABLE = LID_Z - PCB_TOP_Z;

NEEDED_CLEARANCE =
    SWITCH_H +
    SWITCH_SAFE_TRAVEL +
    0.5;

LID_BOSS_H =
    max(
        0,
        NEEDED_CLEARANCE - CLEARANCE_AVAILABLE
    ) + 0.5;

STOP_H =
    TRAVEL -
    SWITCH_SAFE_TRAVEL +
    0.15;

STOP_D = 2.5;

// ---------------------------------------------------------------------
// USB-C CUTOUT
// ---------------------------------------------------------------------

// Sized for a real plug + strain-relief boot
// on the wall the connector actually faces (left, x=0).

USB_CUT_W = 12;
USB_CUT_H = 6.5;

USB_CUT_Z =
    PCB_TOP_Z +
    1.7;

USB_FUNNEL = 1.5;

// ---------------------------------------------------------------------
// ENCLOSURE GEOMETRY
// ---------------------------------------------------------------------

module rounded_box(x, y, z, r = 4) {
    hull() {
        translate([r, r, 0])
        cylinder(r = r, h = z);

        translate([x - r, r, 0])
        cylinder(r = r, h = z);

        translate([r, y - r, 0])
        cylinder(r = r, h = z);

        translate([x - r, y - r, 0])
        cylinder(r = r, h = z);
    }
}

// Generic tab module.
module tab() {
    cube([
        TAB_L,
        TAB_W,
        TAB_HEIGHT
    ]);
}

// ---------------------------------------------------------------------
// PCB STANDOFF
// ---------------------------------------------------------------------

// A mounting post that is ALWAYS connected:
// solid from the case floor up to the PCB's underside,
// so it can never be a floating island.

module standoff(
    x,
    y,
    pilot_d = 3,
    pilot_from_top = 6
) {
    post_h = PCB_TOP_Z - PCB_T;
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

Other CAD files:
mechanical/Exported_20260929/enclosure_lid_oneswitch.stl
mechanical/enclosure_lid_twoswitch.stl
mechanical/enclosure.stl
mechanical/Exported_20260929/enclosure_lid_twoswitch.stl
mechanical/Exported_20260929/assistive_switch_storage_box.stl
mechanical/enclosure_m2hextrap.stl
mechanical/enclosure_buttons.stl
mechanical/enclosure_lid.stl
mechanical/enclosure_m2hextrap.scad

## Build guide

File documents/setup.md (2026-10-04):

---
layout: default
title: Setup & Pairing
---

# Quick Setup & Classroom Use Guide

<!-- web-only -->
**[Download this guide for printing](https://github.com/mrhunsaker/RB_SWITCH/raw/main/RB_Switch_Paraprofessional_Setup_Guide.docx)**

For paraprofessionals and K–12 staff. This page is the same content as the printable guide, `RB_Switch_Paraprofessional_Setup_Guide.docx`. The printable guide is generated from this page (see [CONTRIBUTING](https://github.com/mrhunsaker/RB_SWITCH/blob/main/CONTRIBUTING.md)), so the two stay in sync.
<!-- /web-only -->

> **Before you begin: Android and iOS/iPadOS are different here.**
> The RB Switch has three buttons. On an iPad or iPhone, all three can be set up in one pass. On an Android phone or tablet, the built-in setup only walks you through two of the three buttons, and Switch Access itself must be installed from the Google Play Store first. Section 6 covers the Android steps in full, including the extra step for the third button. Read it even if you've set up switches on Android before.

## At a glance

| Button | Position | Sends | Suggested scanning action |
|---|---|---|---|
| SW1 | Left | Left Arrow | Previous item |
| SW2 | Center | Enter | Select |
| SW3 | Right | Right Arrow | Next item |

- **Bluetooth name:** RB Switch
- **Power:** USB-C or the installed battery. There is no power switch; the RB Switch is on whenever it has power.
- **Charging light (D1):** on while the battery charges from USB-C. It is not a button indicator.
- **If something is wrong:** go to Section 8, then Section 11.

## 1. What the RB Switch does

The RB Switch is a three-button Bluetooth accessibility switch. It connects to a tablet, phone, Chromebook, Mac, or Windows computer and acts like a standard Bluetooth keyboard. The three physical buttons send three different keyboard commands.

| Button | Sends | In a plain text field |
|---|---|---|
| SW1 (left) | Left Arrow | Cursor moves left |
| SW2 (center) | Enter | Enter/Return |
| SW3 (right) | Right Arrow | Cursor moves right |

The RB Switch does not need an app, and it does not need to be turned on. It starts advertising over Bluetooth as soon as it has power.

## 2. Before you start

- Have the student's device nearby (iPad, iPhone, Android device, Chromebook, Mac, or Windows PC).
- Make sure Bluetooth is turned on.
- Make sure the RB Switch has power. It can be powered by USB-C or its installed battery.
- Keep the RB Switch close to the device while pairing. About 1–3 feet is ideal.
- If the RB Switch has already been paired to another nearby device, that device may reconnect to it first. If needed, turn Bluetooth off on the other device or choose Forget on it.
- If the student's device is Android, install or update the Switch Access app from the Google Play Store before you start (see Section 6). This is a change from older Android versions, where the feature was bundled in automatically.

## 3. Connect the RB Switch by Bluetooth

Use the instructions for the student's device below. Look for **RB Switch** in the list of devices. The name is the same on every unit, so if several RB Switches are in the same room, pair one at a time with the others unplugged or out of range.

### iPad or iPhone

1. Open Settings.
2. Tap Bluetooth.
3. Make sure Bluetooth is On.
4. Look under Other Devices for RB Switch.
5. Tap RB Switch.
6. Wait until it shows as Connected.

### Android phone or tablet

1. Open Settings.
2. Open Bluetooth or Connected devices → Bluetooth. The exact wording varies by device.
3. Make sure Bluetooth is On.
4. Look for RB Switch in the available devices list.
5. Tap RB Switch and complete pairing if Android asks you to do so.
6. Confirm that RB Switch shows as connected.

### Windows PC

1. Open Settings.
2. Select Bluetooth & devices.
3. Turn Bluetooth On.
4. Select Add device → Bluetooth.
5. Select RB Switch.
6. Wait for Windows to finish connecting.

### Mac

1. Open System Settings.
2. Select Bluetooth.
3. Turn Bluetooth On.
4. Find RB Switch in the list of nearby devices.
5. Click Connect.

### Chromebook

1. Click the time in the lower-right corner.
2. Open Bluetooth.
3. Turn Bluetooth On.
4. Select RB Switch from the available devices.
5. Complete pairing if prompted.

## 4. Test the three buttons

Before configuring accessibility settings, test the RB Switch in a place where you can see normal keyboard input. For example, open a text field, a simple document, or another application that accepts keyboard commands.

- Press the left button (SW1). The cursor should move left.
- Press the center button (SW2). Enter/Return should be sent.
- Press the right button (SW3). The cursor should move right.

*Note: Do this test before turning on Switch Control or Switch Access. If a button doesn't work here, it won't start working once accessibility scanning is turned on. See Section 8.*

## 5. Set up Switch Control on iPad/iPhone

Use these steps when the student will operate an iPad or iPhone using Apple's Switch Control accessibility feature. Unlike Android, all three RB Switch buttons can be assigned here without any extra steps.

1. Open Settings.
2. Tap Accessibility.
3. Tap Switch Control.
4. Turn Switch Control On.
5. Tap Switches.
6. Tap Add New Switch.
7. Choose External.
8. When the device asks you to activate a switch, press the RB Switch button you want to assign.
9. Choose the action you want that button to perform.
10. Repeat Add New Switch for the other RB Switch buttons you want the student to use.

Suggested mapping: SW1 (Left Arrow) → Move to Previous Item, SW2 (Enter) → Select Item, SW3 (Right Arrow) → Move to Next Item. This uses all three buttons right away.

Full details: [iOS/iPadOS Switch Control](switch-control-ios.md).

## 6. Set up Switch Access on Android

> **Android limits the setup wizard to two switches. Here's how to add the third.**
> Google's Switch Access is now its own app on the Play Store, and its guided setup only ever asks for one or two switches, never three. To use the RB Switch's third button, you finish the two-switch wizard first, then add the third button afterward in a separate settings screen. Steps 1 and 9–10 below are the parts most generic instructions leave out.

1. Open the Google Play Store app and search for Switch Access. Install it, or tap Update if it's already installed. (If your device shows Switch Access under Accessibility without doing this, it may be an older, bundled version. Check the Play Store anyway.)
2. Open Settings.
3. Open Accessibility.
4. Find and tap Switch Access.
5. Turn Switch Access On, and tap Allow when asked to grant the accessibility permission.
6. When the setup wizard runs, choose Bluetooth switch as your switch type, then select RB Switch from the list.
7. The wizard will ask you to choose One switch or Two switch. Choose Two switch.
8. When prompted, press the button you want as Next (recommended: SW3 / right button), then the button you want as Select (recommended: SW2 / center button). Choose a scanning method and finish the wizard.
9. To add the third button (SW1 / left button), leave the wizard and go to: Settings → Accessibility → Switch Access → Settings → Assign switches for scanning → Previous.
10. Press SW1 when prompted, then tap Save.

If a student only needs two functions (scan and select), you can stop after step 8 and simply not use the third button on that device. Nothing else needs to change.

| RB Switch button | Sends | Recommended Switch Access action |
|---|---|---|
| SW1 (left) | Left Arrow | Previous |
| SW2 (center) | Enter | Select |
| SW3 (right) | Right Arrow | Next |

*Note: Android supports up to five assigned switches once you're past the wizard (Next, Select, Previous, and more, depending on scanning method), but the wizard itself only ever asks about one or two. Menu wording can vary by Android version and device manufacturer.*

Full details: [Android Switch Access](switch-access-android.md).

## 7. Using the RB Switch during the school day

- The RB Switch does not need a separate app for basic operation.
- Once paired, keep the student's device within normal Bluetooth range (about 30 feet in open air, less through walls and furniture).
- If the device stops responding, first check whether RB Switch still shows as connected in Bluetooth settings.
- If the RB Switch loses its connection, it starts advertising again by itself. The device usually reconnects without any action.
- A button press made while the RB Switch is not connected is not saved and is not sent later. Check the connection before assuming a button is broken.
- If the student moves between devices, make sure the switch is disconnected from the previous device before pairing it to the new one.
- The three buttons always use the same keyboard mapping: Left Arrow, Enter, Right Arrow. What that mapping *does* on screen depends on how Switch Control or Switch Access is configured on that specific device.
- The RB Switch has no power switch and no sleep mode. Recharge it regularly, and unplug the battery connector (trained staff only) if it will be stored for a long time.

## 8. Quick troubleshooting

Start with the table, then use the matching section below. The online [Troubleshooting](troubleshooting.md) page has more detail.

| What you see | Most likely cause | First thing to try |
|---|---|---|
| RB Switch is not in the Bluetooth list | No power, or already connected elsewhere | Check power; turn Bluetooth off on other nearby devices |
| It is listed but will not connect | Old saved pairing | Forget RB Switch on the device and pair again |
| Connected, but no button works | Connection dropped, or the host is not listening | Reconnect in Bluetooth settings; test in a text field |
| One button does nothing | Switch or solder joint problem | Note which button and report it |
| Only two buttons work on Android | Third switch not assigned yet | Section 6, steps 9–10 |
| Works in a text field but not in Switch Control/Access | Accessibility feature not set up | Re-add the switch (Sections 5–6) |
| Cursor or selection jumps twice | Host-side repeat settings or a worn switch | Check Switch Stabilization/Ignore Repeat; report if it continues |
| Light stays on or does not come on while plugged in | Normal in some cases; see Section 9 | Read Section 9 |

### RB Switch is not listed in Bluetooth

1. Make sure the RB Switch has power. If it runs from its battery, plug in USB-C for a few minutes in case the battery is flat.
2. Wait a few seconds and refresh the Bluetooth device list.
3. Move the RB Switch closer to the student's device.
4. Check whether it is already connected to another nearby device. Only one device can use the RB Switch at a time.
5. If an old RB Switch entry is saved but the device will not connect, choose Forget/Remove this device and pair it again.

### RB Switch is connected, but a button does nothing

- Press each of the three buttons. The expected mapping is SW1 = Left Arrow, SW2 = Enter, SW3 = Right Arrow.
- Check that RB Switch shows Connected in Bluetooth settings. A press made while it is disconnected is lost.
- If all three buttons fail, disconnect and reconnect RB Switch in Bluetooth settings.
- If only one button fails, note which button fails and report that information to the person responsible for equipment support.

### Only two of the three buttons do anything on an Android device

- This is expected unless you completed steps 9–10 in Section 6 (Assign switches for scanning → Previous).
- It is not a sign of a broken button. Check Section 6 before assuming a hardware problem.
- This does not happen on iPad/iPhone, Windows, Mac, or Chromebook.

### The switch works in a text box but not in the student's accessibility app

- Confirm the accessibility feature is turned on.
- Check that the physical button was added as an external switch in the accessibility settings.
- Re-add the switch if necessary and press the requested RB Switch button when the device asks for it.
- If the problem continues, record the device type, operating-system version if known, and which button/action is affected.

### The connection keeps dropping

- Move the RB Switch and the device closer together and away from other wireless equipment such as routers, microwaves, and several other Bluetooth devices.
- Check the battery. Charge it from USB-C for at least an hour and try again.
- Forget RB Switch on the device and pair it again.

### The student moved to a different device

- Disconnect or forget RB Switch on the old device if it keeps reconnecting there.
- Pair RB Switch with the new device.
- Run the three-button test.
- Reconfigure Switch Control or Switch Access on the new device if required.

More: [Troubleshooting](troubleshooting.md).

## 9. Charging and power

The PCB includes USB-C power and a single-cell Li-Po charging circuit. The charge-status light (D1) is a charging indicator. It is not an RGB status light and does not indicate which button was pressed or whether Bluetooth is connected.

- Use the USB-C connection supplied for the device.
- **Charging light on:** the battery is charging from USB-C.
- **Charging light off:** charging is complete, or USB-C is not connected.
- While the switch is plugged in and in use, the charger may take longer to finish and the light may stay on longer than expected. This is normal.
- If the switch is not powering on, try a known-good USB-C power source and cable. If it still does not respond, the battery may be flat or disconnected.
- The RB Switch has no power switch. It is on whenever the battery is connected or USB-C is plugged in.
- Do not open the enclosure or replace the battery unless you are trained and authorized to service the device.
- Do not assume a replacement battery has the correct connector polarity just because the connector fits.

## 10. Daily checklist

1. Check that the RB Switch shows Connected in Bluetooth settings.
2. Press each button once in a text field. Left, Enter, Right.
3. Check that Switch Control or Switch Access is turned on.
4. At the end of the day, plug the RB Switch in to charge.

## 11. Getting help

Before asking for support, write down:

- The device type (for example, iPad 9th generation) and its operating-system version if known.
- Which button or action is affected (SW1, SW2, SW3).
- Whether the problem happens in a plain text field as well as in Switch Control or Switch Access.
- Whether the charging light is on.
- What you have already tried.

Scan the QR code on the enclosure to return to the latest online instructions.

## 12. Technical support / reprogramming (not normally needed by paraprofessionals)

The current production sketch is `firmware/RB_SWITCH_firmware/RB_SWITCH_firmware.ino`. The current GitHub project specifies the following Arduino setup:

- Install Arduino IDE.
- Install the ESP32 Arduino core by Espressif.
- Install the NimBLE-Arduino library, version 2.x.
- Select an ESP32-S3 target; the project documentation normally uses ESP32S3 Dev Module.
- In the Tools menu, set USB CDC On Boot to Enabled so the Serial Monitor works.
- Open the production .ino file, verify it, and upload it using a data-capable USB-C cable.
- If the board does not enter download mode automatically, hold BOOT, press and release RESET, then release BOOT.
- Use Serial Monitor at 115200 baud for diagnostics.

| Switch | GPIO | Keyboard key |
|---|---|---|
| SW1 | GPIO10 | Left Arrow |
| SW2 | GPIO11 | Enter |
| SW3 | GPIO12 | Right Arrow |

If a button mapping, debounce timing, or device name ever needs to change (for example, to better fit a specific student's Switch Access or Switch Control setup), see [Firmware Customization](firmware-customization.md) before asking a technician to make firmware changes.

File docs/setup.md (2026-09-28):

---
layout: default
title: Setup & Pairing
permalink: /setup.html
---

# Quick Setup & Classroom Use Guide

**[Download this file for printing](https://github.com/mrhunsaker/RB_SWITCH/raw/main/RB_Switch_Paraprofessional_Setup_Guide.docx)**

For paraprofessionals and K–12 staff. This page mirrors the printable guide, `RB_Switch_Paraprofessional_Setup_Guide.docx`. Keep the two in sync.

> **Before you begin: Android and iOS/iPadOS are different here.**
> The RB Switch has three buttons. On an iPad or iPhone, all three can be set up in one pass. On an Android phone or tablet, the built-in setup only walks you through two of the three buttons, and Switch Access itself must be installed from the Google Play Store first. Section 6 below covers the Android steps in full, including the extra step for the third button. Read it even if you've set up switches on Android before — this project documents the current Play Store version of Switch Access.

## 1. What the RB Switch does

The RB Switch is a three-button Bluetooth accessibility switch. It connects to a tablet, phone, Chromebook, Mac, or Windows computer and acts like a standard Bluetooth keyboard. The three physical buttons send three different keyboard commands.

| Button | Sends | In a plain text field |
|---|---|---|
| SW1 (left) | Left Arrow | Cursor moves left |
| SW2 (center) | Enter | Enter/Return |
| SW3 (right) | Right Arrow | Cursor moves right |

## 2. Before you start

- Have the student's device nearby (iPad, iPhone, Android device, Chromebook, Mac, or Windows PC).
- Make sure Bluetooth is turned on.
- Make sure the RB Switch has power. It can be powered by USB-C or its installed battery.
- Keep the RB Switch close to the device while pairing — about 1–3 feet is ideal.
- If the RB Switch has already been paired to another nearby device, that device may reconnect to it. If needed, disconnect or turn Bluetooth off on the other device.
- If the student's device is Android, install or update the Switch Access app from the Google Play Store before you start (see Section 6). This is a change from older Android versions, where the feature was bundled in automatically.

## 3. Connect the RB Switch by Bluetooth

Use the instructions for the student's device below. Find **RB Switch** followed by a 3-digit number; it should match the number on the sticker on the bottom of the enclosure.

### iPad or iPhone

1. Open Settings.
2. Tap Bluetooth.
3. Make sure Bluetooth is On.
4. Look under Other Devices for RB Switch.
5. Tap RB Switch.
6. Wait until it shows as Connected.

### Android phone or tablet

1. Open Settings.
2. Open Bluetooth or Connected devices → Bluetooth. The exact wording varies by device.
3. Make sure Bluetooth is On.
4. Look for RB Switch in the available devices list.
5. Tap RB Switch and complete pairing if Android asks you to do so.
6. Confirm that RB Switch shows as connected.

### Windows PC

1. Open Settings.
2. Select Bluetooth & devices.
3. Turn Bluetooth On.
4. Select Add device → Bluetooth.
5. Select RB Switch.
6. Wait for Windows to finish connecting.

### Mac

1. Open System Settings.
2. Select Bluetooth.
3. Turn Bluetooth On.
4. Find RB Switch in the list of nearby devices.
5. Click Connect.

### Chromebook

1. Click the time in the lower-right corner.
2. Open Bluetooth.
3. Turn Bluetooth On.
4. Select RB Switch from the available devices.
5. Complete pairing if prompted.

## 4. Test the three buttons

Before configuring accessibility settings, test the RB Switch in a place where you can see normal keyboard input. For example, open a text field, a simple document, or another application that accepts keyboard commands.

- Press the left button (SW1) — The cursor should move left.
- Press the center button (SW2) — Enter/Return should be sent.
- Press the right button (SW3) — The cursor should move right.

*Note: Do this test before turning on Switch Control or Switch Access. If a button doesn't work here, it won't start working once accessibility scanning is turned on — see Section 8.*

## 5. Set up Switch Control on iPad/iPhone

Use these steps when the student will operate an iPad or iPhone using Apple's Switch Control accessibility feature. Unlike Android, all three RB Switch buttons can be assigned here without any extra steps.

1. Open Settings.
2. Tap Accessibility.
3. Tap Switch Control.
4. Turn Switch Control On.
5. Tap Switches.
6. Tap Add New Switch.
7. Choose External.
8. When the device asks you to activate a switch, press the RB Switch button you want to assign.
9. Choose the action you want that button to perform.
10. Repeat Add New Switch for the other RB Switch buttons you want the student to use.

Suggested mapping: SW1 (Left Arrow) → Move to Previous Item, SW2 (Enter) → Select Item, SW3 (Right Arrow) → Move to Next Item. This uses all three buttons right away.

Full details: [iOS/iPadOS Switch Control]({{ '/switch-control-ios.html' | relative_url }}).

## 6. Set up Switch Access on Android

> **Android limits the setup wizard to two switches. Here's how to add the third.**
> Google's Switch Access is now its own app on the Play Store, and its guided setup only ever asks for one or two switches — never three. To use the RB Switch's third button, you finish the two-switch wizard first, then add the third button afterward in a separate settings screen. Steps 1 and 9–10 below are the parts most generic instructions leave out.

1. Open the Google Play Store app and search for Switch Access. Install it, or tap Update if it's already installed. (If your device shows Switch Access under Accessibility without doing this, it may be an older, bundled version — check the Play Store anyway.)
2. Open Settings.
3. Open Accessibility.
4. Find and tap Switch Access.
5. Turn Switch Access On, and tap Allow when asked to grant the accessibility permission.
6. When the setup wizard runs, choose Bluetooth switch as your switch type, then select RB Switch from the list.
7. The wizard will ask you to choose One switch or Two switch. Choose Two switch.
8. When prompted, press the button you want as Next (recommended: SW3 / right button), then the button you want as Select (recommended: SW2 / center button). Choose a scanning method and finish the wizard.
9. To add the third button (SW1 / left button), leave the wizard and go to: Settings → Accessibility → Switch Access → Settings → Assign switches for scanning → Previous.
10. Press SW1 when prompted, then tap Save.

If a student only needs two functions (scan and select), you can stop after step 8 and simply not use the third button on that device — nothing else needs to change.

| RB Switch button | Sends | Recommended Switch Access action |
|---|---|---|
| SW1 (left) | Left Arrow | Previous |
| SW2 (center) | Enter | Select |
| SW3 (right) | Right Arrow | Next |

*Note: Android supports up to five assigned switches once you're past the wizard (Next, Select, Previous, and more, depending on scanning method), but the wizard itself only ever asks about one or two. Menu wording can vary by Android version and device manufacturer.*

Full details: [Android Switch Access]({{ '/switch-access-android.html' | relative_url }}).

## 7. Using the RB Switch during the school day

- The RB Switch does not need a separate app for basic operation.
- Once paired, keep the student's device within normal Bluetooth range.
- If the device stops responding, first check whether RB Switch still shows as connected in Bluetooth settings.
- If the student moves between devices, make sure the switch is disconnected from the previous device before pairing it to the new one.
- The three buttons always use the same keyboard mapping: Left Arrow, Enter, Right Arrow. What that mapping *does* on screen depends on how Switch Control or Switch Access is configured on that specific device.

## 8. Quick troubleshooting

### RB Switch is not listed in Bluetooth

1. Make sure the RB Switch has power.
2. Wait a few seconds and refresh the Bluetooth device list.
3. Move the RB Switch closer to the student's device.
4. Check whether it is already connected to another nearby device.
5. If an old RB Switch entry is saved but the device will not connect, choose Forget/Remove this device and pair it again.

### RB Switch is connected, but a button does nothing

- Press each of the three buttons. The expected mapping is SW1 = Left Arrow, SW2 = Enter, SW3 = Right Arrow.
- If all three buttons fail, disconnect and reconnect RB Switch in Bluetooth settings.
- If only one button fails, note which button fails and report that information to the person responsible for equipment support.

### Only two of the three buttons do anything on an Android device

- This is expected unless you completed steps 9–10 in Section 6 (Assign switches for scanning → Previous).
- It is not a sign of a broken button — check Section 6 before assuming a hardware problem.
- This does not happen on iPad/iPhone, Windows, Mac, or Chromebook.

### The switch works in a text box but not in the student's accessibility app

- Confirm the accessibility feature is turned on.
- Check that the physical button was added as an external switch in the accessibility settings.
- Re-add the switch if necessary and press the requested RB Switch button when the device asks for it.
- If the problem continues, record the device type, operating-system version if known, and which button/action is affected.

### The student moved to a different device

- Disconnect or forget RB Switch on the old device if it keeps reconnecting there.
- Pair RB Switch with the new device.
- Run the three-button test.
- Reconfigure Switch Control or Switch Access on the new device if required.

More: [Troubleshooting]({{ '/troubleshooting.html' | relative_url }}).

## 9. Charging and power

The current PCB includes USB-C power and a Li-Po charging circuit. The charge-status LED is a charging indicator; it is not an RGB status light and does not indicate which button was pressed.

- Use the USB-C connection supplied for the device.
- If the switch is not powering on, try a known-good USB-C power source/cable.
- Do not open the enclosure or replace the battery unless you are trained and authorized to service the device.
- Do not assume a replacement battery has the correct connector polarity just because the connector fits.

## 10. Technical support / reprogramming (not normally needed by paraprofessionals)

The current production sketch is `firmware/RB_SWITCH_firmware/RB_SWITCH_firmware.ino`. The current GitHub project specifies the following Arduino setup:

- Install Arduino IDE.
- Install the ESP32 Arduino core by Espressif.
- Install the NimBLE-Arduino library.
- Select an ESP32-S3 target; the project documentation normally uses ESP32S3 Dev Module.
- Open the production .ino file, verify it, and upload it using a data-capable USB-C cable.
- If the board does not enter download mode automatically, use the PCB's BOOT and RESET controls according to the ESP32-S3 upload procedure.
- Use Serial Monitor at 115200 baud for diagnostics.

| Switch | GPIO | Keyboard key |
|---|---|---|
| SW1 | GPIO10 | Left Arrow |
| SW2 | GPIO11 | Enter |
| SW3 | GPIO12 | Right Arrow |

If a button mapping, debounce timing, or device name ever needs to change (for example, to better fit a specific student's Switch Access or Switch Control setup), see [Firmware Customization]({{ '/firmware-customization.html' | relative_url }}) before asking a technician to make firmware changes.

Need help? Scan the QR code on the enclosure again to return to the latest online instructions.

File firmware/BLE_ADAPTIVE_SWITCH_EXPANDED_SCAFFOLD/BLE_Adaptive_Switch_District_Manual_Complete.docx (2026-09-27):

BLE ADAPTIVE SWITCH NODE

District Implementation Manual

Corrected & Expanded Edition

Written for teachers, paraeducators, AT specialists, and technology staff

Covers: device basics for the classroom · testing touch, proximity, and switch inputs

iPad/iPhone and Android pairing · firmware flashing · asset management · printable forms

Firmware: BLE_ADAPTIVE_SWITCH_EXPANDED_SCAFFOLD.ino + types_expanded.h

Device: ESP32-S3 SuperMini | BLE Profile: HID Keyboard (NimBLE stack)

Inputs: 6 capacitive touch · 1 proximity sensor · 4 mechanical switch jacks

Published by District Assistive Technology Department

# Table of Contents

# SECTION A — What This Device Does

The BLE Adaptive Switch Node is a small, wireless accessibility device built on the ESP32-S3 SuperMini microcontroller. It lets a student activate physical switches — things they touch, things they move near without touching, and things they press — and turns each activation into a standard Bluetooth keyboard keystroke.

Because it presents itself to the iPad, iPhone, or Android device as an ordinary Bluetooth keyboard, no app needs to be installed. iPadOS/iOS Switch Control and Android Switch Access both recognize it immediately and can map each input to scanning, selection, or navigation actions, exactly as they would for any commercial switch interface.

## A.1 The Three Kinds of Input

Input Type | How Many | How a Student Uses It | HID Keys Sent
Capacitive touch sensor | 6 | Lightly touch the sensor pad — no pressure needed | F1–F6
Proximity sensor | 1 | Move a hand or body part close to the sensor without touching it | F8
Mechanical switch (mono jack) | 4 | Press a standard adaptive switch plugged into a 3.5 mm jack | F9–F12

That is 11 independent inputs in total, and every single one sends a different key. This matters because Switch Control and Switch Access tell switches apart by which key arrives — if two inputs ever sent the same key, the software could not distinguish them.

## A.2 The LED — What Each Color Means

A single RGB indicator light (GPIO 48) gives instant feedback on every activation. The light tells you what TYPE of input just fired, not which specific sensor — this is a deliberate design choice that keeps the color code simple enough to memorize in a few seconds:

LED Color | Meaning
Green | A touch sensor was activated (F1–F6)
Red | The proximity sensor was activated (F8)
Blue | A switch / mono-jack input was activated (F9–F12)
Off / dark | Idle — no recent activation, or not yet connected

Remember it as: GREEN — you touched it. RED — it sensed you nearby. BLUE — you pressed it.

## A.3 What's Inside (Plain-Language Version)

- A small circuit board (ESP32-S3 SuperMini) that runs the program and talks over Bluetooth.
- Up to 6 small touch pads (TTP223 sensors) wired to the board.
- One proximity sensor that detects nearby motion without contact.
- Up to 4 standard 3.5 mm mono-jack sockets for plugging in adaptive switches.
- One small multicolor indicator light.
- A USB-C port for power and (for technology staff) for programming the device.
- An optional rechargeable battery for cable-free use during the school day.

No screen, no buttons to configure, and no companion app. Everything a teacher needs to do day-to-day is in Section B.

# SECTION B — For Teachers & Paraeducators: Daily Use and Testing

This section assumes no technical background. You will not need a computer, the Arduino IDE, or any programming knowledge to do anything described here. Everything in this section can be done with the device itself, the student's iPad/iPhone or Android device, and your own hands.

## B.1 Before You Start

Your technology department has already programmed (“flashed”) the device. You do not do that step — it is covered separately in Section D for IT staff. Your job is to power it on, pair it, test it, and use it.

## B.2 Powering the Device On

1. Plug in the USB-C cable, or switch on the battery if your unit has one.
2. Wait about 10 seconds. The indicator light may blink briefly during startup — this is normal.
3. Once startup finishes, the light goes dark and stays dark until an input is activated or it connects. A dark, idle light is the normal “ready and waiting” state, not a sign of failure.

## B.3 Pairing with an iPad or iPhone

1. On the iPad/iPhone, open Settings → Bluetooth.
2. Turn Bluetooth ON if it isn't already.
3. Under “Other Devices,” look for “BT Switch” (this is the device's default name; your district may have renamed it — see Section N).
4. Tap “BT Switch” to pair.
5. The device moves to “My Devices” and shows “Connected.”

After the first pairing, the iPad and the device reconnect automatically every time both are powered on — you should not need to repeat these steps daily.

## B.4 Pairing with an Android Tablet or Phone

1. On the Android device, open Settings → Connected devices (wording varies slightly by manufacturer/Android version) → Pair new device.
2. Look for “BT Switch” in the list of available devices.
3. Tap to pair. If a pairing code or confirmation prompt appears, accept it.
4. Confirm the device now shows as “Connected” under your paired/connected devices list.

This firmware has been verified on a Nokia G100 running Android 12 with Switch Access, and is expected to work the same way on other Android 9+ devices that support Bluetooth keyboards. If a specific Android device refuses to finish pairing, see Section G.3 — some Android devices need the battery status feature this device provides, and it is already built in.

## B.5 Turning On Switch Control (iPad / iPhone)

1. Open Settings → Accessibility → Switch Control.
2. Turn the Switch Control toggle ON. A scanning cursor will appear on screen.
3. Tap Switches → Add New Switch → External.
4. When prompted, activate the input you want to map (touch a pad, wave near the proximity sensor, or press a switch).
5. Give it a name you'll recognize (e.g., “Left Touch,” “Big Red Switch”) and choose the action it should perform.
6. Repeat for each input the student will use.

## B.6 Turning On Switch Access (Android)

1. If not already installed, install “Switch Access” from the Google Play Store.
2. Open Settings → Accessibility → Switch Access, and turn it ON.
3. Follow the in-app setup to add a switch: activate the desired input when prompted.
4. Assign the action you want that input to perform (e.g., move to next item, select).
5. Repeat for each input the student will use.

## B.7 Testing Each Kind of Input — The Most Important Section for Daily Use

Before any session with a student, and any time something seems “off,” test all three input types. You do not need any tools for this — just the device, and ideally a paired iPad or Android device so you can confirm the on-screen response as well as the LED.

### B.7.1 Testing a Touch Sensor

1. Lightly touch one of the touch pads (labeled Touch 1–6) with a fingertip or knuckle. No pressure is needed — these are capacitive sensors, like a phone screen.
2. Watch the indicator light: it should flash GREEN once.
3. If paired, watch the iPad/Android screen: the Switch Control or Switch Access cursor should respond exactly once per touch.
4. Lift off and touch again to confirm it fires once per touch, not continuously while held.

A touch sensor that never lights up green, or that fires repeatedly on its own without being touched, should be reported — see Section B.11.

### B.7.2 Testing the Proximity Sensor

1. Locate the proximity sensor — it is the small sensor window, separate from the touch pads and switch jacks.
2. Slowly bring a hand or other body part to within a few centimeters (roughly 1–4 inches) of the sensor window. Do not touch it — this sensor is designed to respond to nearness, not contact.
3. Watch the indicator light: it should flash RED once your hand is close enough.
4. Move your hand away. The sensor needs to see you move away before it will register the next activation — this is normal and prevents one long activation from repeating.

If the proximity sensor never lights up red no matter how close you get, it most likely needs technology staff to check its wiring or library configuration — see Section B.11 and Section G.

### B.7.3 Testing a Switch / Button Input

1. Plug a standard adaptive switch (3.5 mm mono plug) into one of the switch jacks (labeled Switch 1–4), if one is not already connected.
2. Press the switch.
3. Watch the indicator light: it should flash BLUE once per press.
4. Release and press again to confirm a single, clean activation each time.

### B.7.4 Quick Test Reference Card

Input Type | How to Test | LED Should Flash | On-Screen Result
Touch (Touch 1–6) | Lightly touch the pad | Green | Cursor moves / item selected, once per touch
Proximity | Hold hand ~1–4 in. away, then move it back | Red | Cursor moves / item selected, once per approach
Switch (Switch 1–4) | Press the connected switch | Blue | Cursor moves / item selected, once per press

## B.8 Daily Startup Checklist

☐ Power on the device and wait for startup to finish (light goes dark and idle).

☐ Confirm the iPad/Android device shows the device as “Connected.”

☐ Test at least one touch input — LED flashes green and the screen responds.

☐ Test the proximity sensor if the student uses it — LED flashes red and the screen responds.

☐ Test at least one switch input if the student uses it — LED flashes blue and the screen responds.

## B.9 Daily Shutdown Checklist

☐ Disconnect the device from the student's work area.

☐ Visually check all cables for damage, kinking, or fraying.

☐ Gently wiggle each connected adaptive switch cable to confirm it is seated firmly.

☐ Power off, or leave charging, per your building's protocol.

☐ Store the device in its designated location.

## B.10 Basic Troubleshooting (No Tech Required)

### A switch or sensor stopped responding mid-session

1. Check the Bluetooth/connection status on the iPad or Android device — it should show “Connected.”
2. If it shows disconnected, tap the device name to reconnect.
3. Check the physical cable between an adaptive switch and its jack — reseat it.
4. Try a different switch jack on the device, if available, to rule out a damaged jack.
5. If still unresponsive, contact your AT specialist or technology staff (Section B.11).

### The device disappeared from the Bluetooth/paired list

1. Power the device off completely, then back on. Wait about 15 seconds.
2. On the tablet, open Bluetooth/Connected devices settings — the device should reappear.
3. Tap to reconnect.
4. If it does not reappear within 30 seconds, try “forgetting” the device and re-pairing from scratch (Section B.3 / B.4).

### The LED never lights up at all, on any input

1. Confirm the device is actually powered — try a different USB-C cable, since many cables are charge-only.
2. If the device otherwise seems to work (it pairs, the screen responds) but the light itself never shows any color, this is most likely a hardware fault with the LED — report it (Section B.11). The device may still be safe to use for now since the LED is feedback only, not required for function.

## B.11 What to Report to Technology or AT Staff

Try the steps in B.10 first. Contact technology or AT staff if:

- The device will not power on after trying a different cable.
- Bluetooth will not reconnect after repeated restarts and re-pairing attempts.
- One or more inputs never register in any test, on any platform.
- There is visible physical damage to the enclosure, sensors, cables, or jacks.
- The proximity sensor never responds, even at very close range.
- The indicator light never illuminates at all, in any color.

# SECTION C — Hardware and GPIO Reference

This section is for AT specialists and technology staff who build, wire, or repair units. It reflects the actual firmware (BLE_ADAPTIVE_SWITCH_EXPANDED_SCAFFOLD.ino / types_expanded.h), not an earlier hardware revision.

## C.1 Hardware Components

Component | Purpose | Notes
ESP32-S3 SuperMini (ESP32S3FH4R2) | Main microcontroller | USB-C, BLE 5.0, in-package flash + PSRAM
TTP223 touch sensor modules (×6) | Capacitive touch input | 3.3V, digital output, active HIGH
I²C proximity sensor (×1) | Proximity input | APDS-9930, APDS-9960, VCNL4040, or VL53L0X — one per build
3.5 mm mono jack sockets (×4) | Adaptive switch input | Tip = signal, Sleeve = GND, INPUT_PULLUP
WS2812 NeoPixel LED | Visual feedback | GPIO 48, controlled by Adafruit NeoPixel
USB-C cable | Power and programming | Must be data-capable for flashing
3.7V 1100mAh LiPo battery (optional) | Cable-free power | Used with a TP4056 charge board

## C.2 GPIO Pin Reference

Signal | GPIO | Mode | HID Key | LED Color
Touch 1 | 1 | INPUT | F1 | Green
Touch 2 | 2 | INPUT | F2 | Green
Touch 3 | 4 | INPUT | F3 | Green
Touch 4 | 5 | INPUT | F4 | Green
Touch 5 | 6 | INPUT | F5 | Green
Touch 6 | 7 | INPUT | F6 | Green
Proximity (I²C) | SDA 8 / SCL 9 | I2C | F8 | Red
Switch 1 | 10 | INPUT_PULLUP | F9 | Blue
Switch 2 | 11 | INPUT_PULLUP | F10 | Blue
Switch 3 | 12 | INPUT_PULLUP | F11 | Blue
Switch 4 | 13 | INPUT_PULLUP | F12 | Blue
NeoPixel LED | 48 | OUTPUT | — | —

GPIO 3 is intentionally NOT used anywhere in this design, even though it would be electrically capable as a 7th touch input. It is a reset-time JTAG strapping pin, and this firmware avoids it entirely rather than relying on a sensor resting in the correct state at boot. As a direct result, F7 is permanently unused — this is by design, not an oversight.

## C.3 Reserved / Avoided Pins

GPIO | Reason
0 | BOOT button / boot-mode strapping
3 | JTAG-source strapping at reset (see callout above)
19 | USB D−
20 | USB D+
45 | VDD_SPI strapping (flash voltage)
46 | Boot-mode strapping (input-only)
48 | NeoPixel RGB LED (in use)

## C.4 Firmware Behavior Summary

- 35 ms software debounce on all 11 inputs, shared through one debounce routine.
- Edge-triggered: a keystroke fires once on activation, not repeatedly while held.
- Automatic BLE reconnection — the device re-advertises immediately if the host disconnects.
- LED fades smoothly toward its target color and fades back to off 250 ms after the last event, rather than snapping on/off.
- A standard Battery Service (UUID 0x180F, fixed at 100%) is included specifically because some Android hosts will not complete BLE HID pairing without one.

# SECTION D — Arduino IDE Setup and Firmware Flashing

This section is for technology staff only. Teachers and paraeducators do not need to perform any of these steps for normal classroom use.

## D.1 Prerequisites

Required hardware: ESP32-S3 SuperMini, a data-capable USB-C cable, a Windows/macOS/Linux computer.

Required files: BLE_ADAPTIVE_SWITCH_EXPANDED_SCAFFOLD.ino and types_expanded.h, in the same folder.

Internet connection: required for the initial board-support and library installation.

Estimated setup time: 30–60 minutes, mostly download/install waits.

## D.2 Install Arduino IDE

Download from https://www.arduino.cc/en/software for your operating system, run the installer with default options, and allow installation of USB/serial drivers when prompted.

## D.3 Install ESP32 Board Support

1. In Arduino IDE, open File → Preferences, and in “Additional Boards Manager URLs” paste: https://raw.githubusercontent.com/espressif/arduino-esp32/gh-pages/package_esp32_index.json
2. Open Tools → Board → Boards Manager, search “esp32,” and install “ESP32 by Espressif Systems.”

## D.4 Install Required Libraries

Open Sketch → Include Library → Manage Libraries and install each of the following:

Library | Required For | Notes
NimBLE-Arduino | BLE HID keyboard stack | by h2zero
Adafruit NeoPixel | Status LED | by Adafruit
SparkFun APDS9960 | Proximity sensor (default build) | Covers both APDS-9930 and APDS-9960
Adafruit VCNL4040 | Proximity sensor (alternate) | Only if using VCNL4040 instead
Adafruit VL53L0X | Proximity sensor (alternate) | Only if using VL53L0X instead

Wire is bundled with the ESP32 Arduino core and does not need separate installation.

## D.5 Choose the Proximity Sensor

Near the top of the .ino file, exactly one of the following four lines must be uncommented to match the physical sensor installed in the unit:

#define USE_APDS9930 (default) // #define USE_VCNL4040 // #define USE_VL53L0X // #define USE_APDS9960

If you change the sensor, also check PROX_I2C_ADDR and PROX_THRESHOLD a few lines below — each sensor family uses a different I²C address and a different practical threshold.

## D.6 Prepare and Open the Project

1. Place BLE_ADAPTIVE_SWITCH_EXPANDED_SCAFFOLD.ino and types_expanded.h together in one folder.
2. In Arduino IDE, choose File → Open and select the .ino file. types_expanded.h will open automatically in an adjacent tab — this is expected.

## D.7 Connect, Select Board and Port

1. Connect the board with a known data-capable USB-C cable.
2. Tools → Board → ESP32 Arduino → ESP32S3 Dev Module.
3. Tools → Port → select the port that appeared when the board was connected.

Selecting any board type other than ESP32S3 Dev Module is the most common cause of first-time compile or upload failure.

## D.8 Compile and Upload

1. Click Verify (✓) first. Expected result: “Done compiling.”
2. Click Upload (→). Expected final message: “Hard resetting via RTS pin…”
3. If upload fails on a fresh board, hold BOOT, briefly press and release RESET, release BOOT, then retry Upload within about 3 seconds.

### D.8.1 Common Compilation Errors

Error Message | Cause | Resolution
NimBLEDevice.h: No such file or directory | NimBLE-Arduino not installed | Install NimBLE-Arduino via Library Manager
Adafruit_NeoPixel.h: No such file or directory | NeoPixel library not installed | Install Adafruit NeoPixel via Library Manager
types_expanded.h: No such file or directory | Header not in the same folder | Move both files into one folder together
HIDKeyboardTypes.h: No such file or directory | Header is included but unused | Delete that #include line; no named constants from it are used
SparkFun_APDS9960.h: No such file or directory | Proximity library not installed, or wrong #define selected | Install the library matching the #define in Section D.5

## D.9 Serial Monitor Verification

Open Tools → Serial Monitor, set the baud rate to 115200, and reset the board. You should see setup logging end with “=== SETUP COMPLETE ===” and “=== BLE READY, ADVERTISING ===.” Every touch, proximity, and switch activation also logs its GPIO and assigned key here — this is the most reliable way to confirm a specific sensor by number, since the LED only reports input type.

# SECTION E — iPad / iOS Pairing and Switch Control Configuration (Detailed)

This is the detailed reference version of Section B.3/B.5, intended for AT specialists configuring a unit for a specific student for the first time.

## E.1 Pair the Device

1. Power on the BLE Switch Node.
2. On the iPad, open Settings → Bluetooth and ensure Bluetooth is ON.
3. Under Other Devices, locate “BT Switch” and tap to pair.
4. Accept any pairing confirmation prompts.
5. Confirm the device appears under My Devices showing Connected.

After first pairing, the iPad and switch node reconnect automatically on future power-ups, as long as the iPad has not “forgotten” the device.

## E.2 Configure Switch Control

### E.2.1 Enable Switch Control

1. Open Settings → Accessibility → Switch Control.
2. Tap the Switch Control toggle to turn it ON. The scanning cursor appears on screen.

### E.2.2 Add Each Switch

1. Within Switch Control settings, tap Switches → Add New Switch → External.
2. When prompted “Activate the switch,” touch the desired sensor or press the connected adaptive switch.
3. Enter a descriptive name (e.g., “Left Touch,” “Proximity – Head Approach,” “Right Switch”).
4. Select the Switch Control action to assign (e.g., Select Item, Move to Next Item).
5. Tap Save, and repeat for each input you want configured.

## E.3 Verify Input Operation

With Bluetooth connected, Switch Control enabled, and the Serial Monitor open (if a computer is available), activate each input and confirm:

Input Activated | Expected Serial Output | LED Color | Expected iPad Action
Touch 1–6 (any) | TOUCH n GPIO## -> F# (0x3A–0x3F) | Green | Configured Switch Control action fires once
Proximity | PROX near -> F8 (0x41) | Red | Configured Switch Control action fires once
Switch 1–4 (any) | SWITCH n GPIO## -> F# (0x42–0x45) | Blue | Configured Switch Control action fires once

# SECTION F — Android Pairing and Switch Access Configuration (Detailed)

This is the detailed reference version of Section B.4/B.6.

## F.1 Pair the Device

1. Power on the BLE Switch Node.
2. On the Android device, open Settings → Connected devices → Pair new device (menu names vary by manufacturer and Android version).
3. Locate “BT Switch” in the list of nearby devices and tap to pair.
4. Accept any confirmation/pairing-code prompts.
5. Confirm the device shows as Connected in the Connected devices list.

If pairing stalls or silently fails on a specific Android device, confirm the firmware build includes the Battery Service (UUID 0x180F) described in Section C.4 — this was required to complete pairing on the Nokia G100 / Android 12 reference device used to verify this firmware.

## F.2 Install and Enable Switch Access

1. Install “Switch Access” from the Google Play Store if not already present.
2. Open Settings → Accessibility → Switch Access and turn it ON.
3. Follow the in-app prompts to add a new switch: activate the desired physical input when asked.
4. Assign the action (e.g., Move to next item, Select) for that input.
5. Repeat for each input the student will use.

## F.3 Verify Input Operation

Input Activated | LED Color | Expected Android Action
Touch 1–6 (any) | Green | Configured Switch Access action fires once
Proximity | Red | Configured Switch Access action fires once
Switch 1–4 (any) | Blue | Configured Switch Access action fires once

# SECTION G — Troubleshooting Flowcharts and Escalation

## G.1 Device Will Not Power On

Step | Check | If NO — Action | If YES — Action
1 | USB-C cable connects device to computer/charger | Use a known data-capable cable | Proceed to step 2
2 | Does any LED appear during startup? | Try a different USB port/charger | Proceed to step 3
3 | Still dark after two cables, two sources? | Replace ESP32-S3 SuperMini board | Proceed to step 4
4 | Serial Monitor shows startup messages? | Reflash firmware per Section D | Device is functional — check BLE

## G.2 Device Will Not Upload (Flashing Failure)

Step | Check | If FAIL — Action | If PASS — Action
1 | Board set to ESP32S3 Dev Module? | Change board selection | Proceed to step 2
2 | Correct serial port selected? | Replug USB, refresh port list | Proceed to step 3
3 | Upload attempt — any error? | Try manual BOOT + RESET entry (Section D.8) | Proceed to step 4
4 | Still failing after BOOT entry? | Reinstall the ESP32 board package | Upload complete

## G.3 Bluetooth Will Not Connect

Step | Check | Negative — Action | Positive — Action
1 | Serial Monitor shows ADVERTISING STARTED? | Reflash firmware | Proceed to step 2
2 | “BT Switch” visible in the host's Bluetooth scan? | Reboot device, rescan on host | Proceed to step 3
3 | Pairing attempt succeeds? | Forget device on host, reboot device, retry | Proceed to step 4
4 | Host shows Connected? | Enable Switch Control / Switch Access | Configure switches

Android-specific: if pairing repeatedly fails at the “connecting…” stage specifically on Android (but works fine on iPad), confirm the firmware build includes the Battery Service — some Android BLE HID stacks require it to finalize the connection.

## G.4 Inputs Not Registering

Symptom | First Check | Second Check | Escalate If
Touch sensor unresponsive | Serial Monitor for TOUCH messages | Re-seat TTP223 wiring | No Serial output — replace TTP223
Proximity sensor unresponsive | Serial Monitor for an I²C error code at startup | Verify SDA=8/SCL=9 wiring and correct #define (Section D.5) | Sensor still silent — replace sensor or check address
Switch unresponsive | Test switch continuity with a multimeter | Check 3.5 mm jack seating | No continuity — replace switch or cable
Input fires repeatedly on its own | Check for debris/moisture on a touch pad | Confirm 35 ms debounce is intact in firmware | Replace sensor if still erratic
Wrong on-screen action triggered | Verify Switch Control / Switch Access assignment | Re-assign the action in settings | Contact AT specialist

## G.5 Escalation Matrix

Issue Level | Who Handles | Response Time | Escalate To
Bluetooth reconnect failure | Teacher or paraeducator | Immediate — reboot device | Tech staff if unresolved in 5 min
A switch/sensor not registering | Teacher or paraeducator | Immediate — check cable/test | AT specialist if hardware suspected
Firmware reflash required | Technology staff | Same school day | District AT coordinator
Hardware damage / board failure | Technology staff | Same school day | Replacement unit dispatch
New device deployment | Technology staff | Per deployment schedule | District IT for inventory entry
Student evaluation / configuration change | AT specialist | Per IEP timeline | Special education director

# SECTION H — Formal Acceptance Testing Procedure

Every unit must pass acceptance testing before assignment to a student. This procedure verifies firmware correctness, all 11 inputs, and connectivity on whichever platform(s) the unit will be used with.

## H.1 Pre-Deployment Acceptance Form

Field | Entry
Device ID / Asset Number
Bluetooth Advertised Name
Firmware Source File | BLE_ADAPTIVE_SWITCH_EXPANDED_SCAFFOLD.ino
ESP32 Chip ID (from Serial Monitor)
Proximity Sensor Type Installed
Target Platform(s) | ☐ iPad/iOS ☐ Android
Date of Testing
Technician Name
Assigned Student / Room (if known)

## H.2 Hardware Checks

☐ Visual inspection — no physical damage, loose wiring, or cracked enclosure

☐ USB-C connector seated and functional

☐ All 6 TTP223 touch sensors present and attached

☐ Proximity sensor present, attached, and wired to SDA=8 / SCL=9

☐ All 4 mono switch jacks present and undamaged

☐ NeoPixel LED present and not physically damaged

## H.3 Firmware and Startup Checks

☐ Device powers on — startup sequence visible

☐ Serial Monitor at 115200 baud shows the full setup sequence ending in “=== SETUP COMPLETE ===”

☐ “=== BLE READY, ADVERTISING ===” message confirmed

☐ Proximity sensor initializes without an I²C error in Serial Monitor

## H.4 Bluetooth Checks

☐ “BT Switch” (or custom name) visible in target device's Bluetooth scan

☐ Pairing completes without errors

☐ Target device shows Connected status

☐ Power-cycle reconnection test: power off, power back on, host reconnects automatically within ~10 seconds

## H.5 Input Verification — All 11 Inputs

☐ Touch 1 (GPIO 1) → F1, Serial shows TOUCH 0, LED flashes Green

☐ Touch 2 (GPIO 2) → F2, Serial shows TOUCH 1, LED flashes Green

☐ Touch 3 (GPIO 4) → F3, Serial shows TOUCH 2, LED flashes Green

☐ Touch 4 (GPIO 5) → F4, Serial shows TOUCH 3, LED flashes Green

☐ Touch 5 (GPIO 6) → F5, Serial shows TOUCH 4, LED flashes Green

☐ Touch 6 (GPIO 7) → F6, Serial shows TOUCH 5, LED flashes Green

☐ Proximity → F8, Serial shows PROX near, LED flashes Red

☐ Switch 1 (GPIO 10) → F9, Serial shows SWITCH 0, LED flashes Blue

☐ Switch 2 (GPIO 11) → F10, Serial shows SWITCH 1, LED flashes Blue

☐ Switch 3 (GPIO 12) → F11, Serial shows SWITCH 2, LED flashes Blue

☐ Switch 4 (GPIO 13) → F12, Serial shows SWITCH 3, LED flashes Blue

## H.6 Switch Control / Switch Access Integration Test

☐ Switch Control (iPad) or Switch Access (Android) enabled on the target device

☐ All intended inputs assigned in the accessibility settings

☐ Scanning/selection responds correctly to touch inputs

☐ Scanning/selection responds correctly to the proximity sensor

☐ Scanning/selection responds correctly to switch inputs

## H.7 Final Result

Result | Technician Signature | Date
PASS / FAIL (circle one)

If FAIL: document the failure mode below and do not deploy the unit until resolved.

Failure notes (continue on back if needed) | Date reviewed

# SECTION I — Asset Management

## I.1 Inventory Record Template

Maintain one row per physical device in the district inventory system (spreadsheet, database, or asset management platform).

Field | Description / Format
Asset Number | District-assigned unique identifier (e.g., AT-2026-001)
Bluetooth Name | Advertised BLE name programmed in firmware (default: BT Switch)
Proximity Sensor Type | APDS-9930 / APDS-9960 / VCNL4040 / VL53L0X
Build Date | Date unit was assembled and flashed
Acceptance Test Date | Date of most recent acceptance test (Section H)
Acceptance Test Result | PASS or FAIL
Current Building / Room | Building name or code and room number
Assigned Staff | Teacher or AT specialist name
Assigned Student | Student ID only — never the student's name
Last Inspection Date | Date of most recent monthly inspection
Next Inspection Due | Calculated 30 days from last inspection
Decommission Date | Date unit was retired from service

## I.2 Device Checkout Form

Complete when any unit leaves the technology department or changes assignment.

Field | Entry
Asset Number
Bluetooth Name
Checked Out To (Staff Name)
Building / Room
Student ID (if assigned)
Date Checked Out
Expected Return Date (if temporary)
Condition at Checkout | Good / Minor wear / Needs repair

Technology Staff Signature / Date | Receiving Staff Signature / Date

# SECTION J — Paraeducator Quick Reference Card

PRINT THIS PAGE AND KEEP IT WITH THE DEVICE. Laminate for durability.

## Every Morning

☐ Power on the switch node

☐ Host device (iPad or Android) shows Connected

☐ Activate one touch input — LED flashes Green, screen responds

☐ Activate the proximity sensor (if used) — LED flashes Red, screen responds

☐ Activate one switch input (if used) — LED flashes Blue, screen responds

## LED Color Guide

LED Color | What It Means
Green | A touch sensor (Touch 1–6) was activated
Red | The proximity sensor was activated
Blue | A switch (Switch 1–4) was activated
Dark / Off | No input, or no connection yet

## If a Switch Stops Working

Try This First | Then Try | Then Call
Check Bluetooth — shows Connected? | Reboot device: power off, wait 10 sec, power on | AT specialist or technology staff
Wiggle the cable at the jack | Try a different jack on the device | Technology staff if hardware issue
Restart Switch Control/Access: OFF, wait 5 sec, ON | Forget and re-pair the device | AT specialist if software/config issue

## If the Device Disappears from the Paired List

1. Power off the switch node.
2. Wait 10 seconds.
3. Power it back on.
4. Open Bluetooth/Connected devices settings on the host.
5. The device name should reappear — tap to reconnect.

## Who to Call

Situation | Contact
Bluetooth will not reconnect after restart | Technology Department
A switch is not working — hardware suspected | Technology Department
Student's scanning pattern needs adjustment | AT Specialist
Switch Control / Switch Access actions need reconfiguring | AT Specialist or Teacher
Physical damage to the device | Technology Department

# SECTION K — Technology Department Maintenance Procedures

## K.1 Monthly Maintenance Checklist

Complete for every active unit each calendar month. File completed checklists in the device folder.

☐ Confirm firmware matches the district-approved version

☐ Power on — complete startup sequence visible in Serial Monitor

☐ Bluetooth advertisement visible from a host scan

☐ Pair or reconnect — host shows Connected

☐ Touch 1–6 each activate — correct Serial output and Green LED

☐ Proximity sensor activates — correct Serial output and Red LED

☐ Switch 1–4 each activate — correct Serial output and Blue LED

☐ Power-cycle reconnection test passes

☐ Physical inspection — no damage

Technician Signature | Date

## K.2 Quarterly Maintenance

- Physical inspection of all units: enclosure, connectors, cables.
- Full inventory audit: confirm physical count matches database records.
- Confirm all units run the current district-approved firmware version.
- Review incident reports filed since the last quarterly review.
- Update inventory records with current building/room/staff assignments.

## K.3 Annual Maintenance

- Reflash all units with the then-current district-approved firmware.
- Complete a full acceptance test (Section H) on every unit after reflashing.
- Update the firmware version log (Section O) with the annual version.
- Review and update training materials if firmware behavior changed.
- Conduct a full inventory audit and decommission damaged/obsolete units.

## K.4 Firmware Update Approval Form

Field | Entry
New Firmware Version / Filename
Previous Firmware Version / Filename
Date of Change
Summary of Changes
Testing Completed By
Number of Units Tested
Pass Rate
Approved By (Technology Director)
Approved By (AT Coordinator)
Deployment Date

Technology Director Signature / Date | AT Coordinator Signature / Date

# SECTION L — AT Specialist Evaluation Form

Completed by the Assistive Technology Specialist when evaluating a student's use of the BLE Adaptive Switch Node.

FERPA NOTICE: This form contains student-specific information. Store per district FERPA policies. Do not attach to or store with the device hardware.

## L.1 Student and Device Information

Field | Entry
Student ID (do not write name on device forms)
Evaluation Date
AT Specialist Name
IEP Meeting Date (if applicable)
Device Asset Number Used During Evaluation
Target Platform | ☐ iPad/iOS ☐ Android

## L.2 Access Method Evaluated

☐ Capacitive touch sensors (one or more of Touch 1–6)

☐ Proximity sensor

☐ Mechanical switches via mono jack (one or more of Switch 1–4)

☐ Combination of touch, proximity, and/or switch

☐ Access method currently under evaluation — not yet determined

### L.2.1 Physical Positioning

Describe switch or sensor placement observed during evaluation:

### L.2.2 Accuracy

Metric | Observation
Correct activations per 10 attempts
Unintended activations per 10 attempts
Average time from intent to activation
Consistent activation force / approach distance? | Yes / No / Variable

### L.2.3 Fatigue

Metric | Observation
Duration of sustained use before fatigue signs
Observed fatigue indicators
Recommended maximum session length

### L.2.4 Student Response to LED Feedback

☐ Student notices and responds to LED color changes

☐ LED feedback does not appear to influence student behavior

☐ LED feedback is distracting — consider covering or disabling

## L.3 Recommendations

Switch configuration recommendation for IEP:

Positioning recommendation:

Training recommendation for staff:

Follow-up evaluation recommended: Yes / No If yes, within: ________ weeks

AT Specialist Signature | Date

# SECTION M — FERPA and Student Privacy Guidance

## M.1 What FERPA Requires

The Family Educational Rights and Privacy Act (FERPA) prohibits unauthorized disclosure of personally identifiable information from student education records. Technology staff and educators must follow this section when deploying the BLE Adaptive Switch Node.

## M.2 What Must Not Be Stored on the Device

The ESP32-S3 SuperMini has no non-volatile storage accessible to the firmware beyond the program flash itself. No student information of any kind is stored on or transmitted by the firmware. District staff must still follow the naming restrictions below.

### M.2.1 Bluetooth Device Names Must Not Contain:

- Student full names or partial names
- Student ID numbers
- Any medical diagnosis or disability category
- Classroom identifiers that would allow identification of a specific student

Compliant Naming Examples | Non-Compliant Naming Examples
BT Switch B1-001 | BT Switch John Smith (contains a student name)
BT Switch Room 14A | Switch 042839 (contains a student ID)
BT Switch 07 | CP Switch Room 14 (contains a disability category)

## M.3 Inventory Systems

- Inventory databases linking Asset Numbers to student identifiers must comply with district FERPA data governance policies.
- Printed inventory sheets with student ID assignments must be stored securely, never left in classrooms.
- Device labels must use asset numbers only, never student names.

## M.4 Evaluation Records

- AT specialist evaluation forms (Section L) contain student-identifiable information and must be stored in the student's file per FERPA requirements.
- Do not photograph, scan, or transmit these forms through non-secure channels.
- Completed evaluation forms must not be left with the physical device or in unsecured classrooms.

## M.5 Questions

Contact your district FERPA compliance officer or special education director with any questions about whether a specific practice complies with FERPA.

# SECTION N — Multi-Building Deployment Standards

## N.1 Device Naming Convention

When deploying multiple units across buildings, program a unique Bluetooth name into each unit before flashing to prevent confusion when several devices are powered on in the same space.

Format: BT Switch [Building Code]-[Unit Number] — Examples: BT Switch B1-001, BT Switch B1-002, BT Switch ES-014, BT Switch MS-003

## N.2 How to Change the Bluetooth Name

Before compiling firmware for a specific unit, locate this line near the top of setupBLE() in the .ino file:

NimBLEDevice::init("BT Switch");

Change the string to the unit's assigned name, for example:

NimBLEDevice::init("BT Switch B1-001");

Compile and flash. The advertised name (set elsewhere via advData.setName(...) in the same function) should be updated to match. Each unit then advertises its unique name.

## N.3 Central Inventory Database

Maintain a single district-level inventory tracking all units regardless of building, including at minimum: asset number, Bluetooth name, current building/room/staff, student ID assignment (secured per FERPA), proximity sensor type, and last acceptance test date.

## N.4 Cross-Building Transfer Procedure

1. Update the inventory record with the new building, room, and staff assignment.
2. Confirm the Bluetooth name is appropriate for the new location (rename in firmware if needed).
3. Complete a transfer inspection using the monthly checklist (Section K.1).
4. Notify the receiving building's AT specialist of the transfer.
5. Confirm the receiving host device can successfully pair or reconnect.

# SECTION O — Change Management and Firmware Version Control

## O.1 Firmware Version Log

Record every firmware version ever deployed district-wide. Never delete previous entries.

Version | Release Date | Approved By | Change Summary | Rollback Procedure
2.0.0 (Expanded Scaffold, board-verified) | | | 11-input redesign: 6 touch + 1 proximity + 4 switch; 3-color LED scheme; Battery Service added for Android | Section O.3

## O.2 Change Approval Process

- Technology staff or AT coordinator identifies the need for a firmware change.
- The change is documented and tested on at least 2 units before broad deployment.
- Technology Director and AT Coordinator review and sign the Firmware Update Approval Form (Section K.4).
- Approved firmware is deployed to all units within the designated maintenance window.
- All units are acceptance tested post-flash (full or abbreviated, per supervisor direction).
- The version log (O.1) is updated.

## O.3 Rollback Procedure

1. Locate the previous approved firmware source files in district technology archive storage.
2. Flash all affected units with the previous version using the standard procedure (Section D).
3. Document the rollback in the firmware version log with date and reason.
4. Do not deploy the problem version to additional units until the issue is resolved.

Retain the full source for every version ever deployed (both the .ino and the matching types_expanded.h) in district network storage, not only on individual technicians' computers. Losing a previous version removes the ability to roll back.

# SECTION P — Printable Appendices

## Appendix A — Device Checkout Form

(See Section I.2 for the full form. Reproduce this page for daily use.)

Field | Entry
Asset Number
Bluetooth Name
Date Checked Out
Checked Out To
Building / Room
Student ID
Condition at Checkout | Good / Minor wear / Needs repair
Expected Return Date

Borrowing Staff Signature / Date | Technology Staff Signature / Date

## Appendix B — Classroom Daily Verification Form

Teacher or paraeducator completes daily. Keep with the device or in the classroom binder.

Date | Powered On | Connected | Platform | Inputs Tested | Issue Noted | Initials
| ☐ | ☐ | iPad / Android | ☐ Touch ☐ Prox ☐ Switch
| ☐ | ☐ | iPad / Android | ☐ Touch ☐ Prox ☐ Switch
| ☐ | ☐ | iPad / Android | ☐ Touch ☐ Prox ☐ Switch
| ☐ | ☐ | iPad / Android | ☐ Touch ☐ Prox ☐ Switch
| ☐ | ☐ | iPad / Android | ☐ Touch ☐ Prox ☐ Switch
| ☐ | ☐ | iPad / Android | ☐ Touch ☐ Prox ☐ Switch
| ☐ | ☐ | iPad / Android | ☐ Touch ☐ Prox ☐ Switch
| ☐ | ☐ | iPad / Android | ☐ Touch ☐ Prox ☐ Switch

## Appendix C — Incident Report Form

Field | Entry
Asset Number
Date of Incident
Reported By (name and role)
Building / Room
Student ID (if involved)
Description of Incident
Immediate Action Taken
Follow-up Required? | Yes / No
Assigned To
Resolution Date
Resolution Summary

Reporting Staff Signature / Date | Technology Staff Signature / Date

## Appendix D — Annual Inspection Form

☐ Enclosure — no cracks, loose parts, or sharp edges

☐ USB-C connector functional for charging and data

☐ All 6 TTP223 touch sensors present and responsive

☐ Proximity sensor present, wired, and responsive

☐ All 4 mono switch jacks present and functional

☐ NeoPixel LED illuminates Green / Red / Blue correctly

☐ Full startup sequence confirmed in Serial Monitor

☐ Bluetooth advertising and pairing functional on intended platform(s)

☐ All 11 inputs verified per the Acceptance Test (Section H)

☐ Firmware version matches the current district-approved version

☐ Inventory record updated

Annual Inspection Technician / Date | Technology Director Approval / Date

## Appendix E — Firmware Update Approval Form

(See Section K.4 for the full form. Reproduce this page as needed.)

Field | Entry
New Firmware Version / Filename
Previous Firmware Version / Filename
Summary of Changes
Test Units Count
Test Pass Rate
Approved By — Technology Director
Approved By — AT Coordinator
Deployment Date
Rollback Instructions (attach or reference)

Technology Director Signature / Date | AT Coordinator Signature / Date

## Appendix F — AT Evaluation Worksheet (Abbreviated Field Copy)

(Full form in Section L. This is a condensed field copy for use during evaluation sessions.)

Field | Entry
Student ID
Evaluation Date
AT Specialist
Device Asset Number
Platform | iPad / Android
Access Method Evaluated | Touch / Proximity / Switch / Combination
Correct activations / 10 trials
Unintended activations / 10 trials
Fatigue threshold observed
Recommended switch configuration
Follow-up needed? | Yes / No — Within: ___ weeks

AT Specialist Signature | Date

BLE Adaptive Switch Node — District Implementation Manual Corrected & Expanded Edition

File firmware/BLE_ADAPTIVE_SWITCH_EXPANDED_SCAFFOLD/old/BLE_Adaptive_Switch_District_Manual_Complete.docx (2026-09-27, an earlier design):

BLE ADAPTIVE SWITCH NODE

District Deployment Manual

Expanded Edition

Comprehensive guide for teachers, paraeducators, AT specialists,

technology staff, and district administrators.

Covers: Arduino IDE setup · Firmware flashing · iPad pairing · District deployment

Asset management · Staff training · Compliance · Printable forms

Firmware: BLE_TTP223_SWITCH_FUNCTION_STATE_MODEL

Device: ESP32-S3 Supermini | BLE Profile: HID Keyboard

Published by District Assistive Technology Department

# Table of Contents

# SECTION A — SYSTEM DOCUMENTATION

## A.1 What This Device Does

The BLE Adaptive Switch Node is a small, wireless accessibility device built on the ESP32-S3 Supermini microcontroller. It bridges physical switch inputs — capacitive touch sensors and adaptive switches — to Apple iPads and iPhones through Bluetooth Low Energy (BLE) using the standard HID Keyboard profile.

Students who cannot use a standard touchscreen can activate physical switches to drive all of iPadOS Switch Control, including scanning, selection, and full app navigation.

### A.1.1 HID Keyboard Mapping

Input | Bluetooth Action Sent | Default Switch Control Function
Touch Sensor 1 / Switch Jack 1 | Shift + Tab | Move to previous item
Touch Sensor 2 / Switch Jack 2 | Tab | Move to next item / Scan
Touch Sensor 3 / Switch Jack 3 | Enter | Select highlighted item

### A.1.2 Bluetooth Identity

Default Bluetooth advertisement name: BT Switch Node

Profiles supported: BLE HID Keyboard

Bonding: Enabled (reconnects automatically on power-up)

Range: Approximately 10 meters line-of-sight

## A.2 Hardware Components

Component | Purpose | Notes
ESP32-S3 Supermini | Main microcontroller | USB-C, BLE 5.0
TTP223 touch sensor modules (x3) | Capacitive touch input | 3.3V, digital output
3.5 mm mono jack sockets (x3) | Adaptive switch input | Tip = signal, Sleeve = GND
WS2812B NeoPixel LED | Visual feedback | GPIO 48, controlled by Adafruit NeoPixel
USB-C cable | Power and programming | Data-capable cable required for flashing

### A.2.1 GPIO Pin Reference

Signal | GPIO | Mode | Connected To
Touch 1 | GPIO 4 | INPUT | TTP223 OUT pin
Touch 2 | GPIO 5 | INPUT | TTP223 OUT pin
Touch 3 | GPIO 6 | INPUT | TTP223 OUT pin
Switch Jack 1 | GPIO 10 | INPUT_PULLUP | 3.5 mm jack tip
Switch Jack 2 | GPIO 11 | INPUT_PULLUP | 3.5 mm jack tip
Switch Jack 3 | GPIO 12 | INPUT_PULLUP | 3.5 mm jack tip
NeoPixel LED | GPIO 48 | OUTPUT | WS2812B DIN

### A.2.2 LED Status Colors

Activation | LED Color | Meaning
Touch Sensor 1 | Purple | Shift+Tab sent
Touch Sensor 2 | Red | Tab sent
Touch Sensor 3 | Green | Enter sent
Switch Jack 1 | Blue | Shift+Tab sent
Switch Jack 2 | Cyan | Tab sent
Switch Jack 3 | Yellow | Enter sent
No connection | Off / slow pulse | Advertising, no host paired

## A.3 Firmware Behavior

- 35 ms software debounce on all inputs prevents false triggers
- Automatic BLE reconnection — device re-advertises if host disconnects
- Bluetooth bonding — iPad remembers the device after first pairing
- Non-blocking LED fades — switch inputs remain responsive during LED animation
- Touch sensors: active HIGH (TTP223 output goes HIGH on touch)
- Switch jacks: active LOW (INPUT_PULLUP; switch closure pulls GPIO to ground)
- Firmware converts both input types to a consistent Pressed = TRUE model internally

# SECTION B — ARDUINO IDE SETUP AND FIRMWARE FLASHING

## B.1 Prerequisites

Required hardware: ESP32-S3 Supermini, USB-C data cable, Windows/macOS/Linux computer

Required files: BLE_TTP223_SWITCH_FUNCTION_STATE_MODEL.ino and types.h

Internet connection required for initial installation of board support and libraries.

Estimated total setup time: 30–60 minutes (most time is download/install waits).

## B.2 Install Arduino IDE

### B.2.1 Download

Navigate to: https://www.arduino.cc/en/software

Operating System | Download Target
Windows 10/11 (64-bit) | Windows Win 10 and newer, 64-bit
macOS Intel | macOS Intel
macOS Apple Silicon (M1/M2/M3) | macOS Apple Silicon
Linux | Appropriate Linux AppImage or package

### B.2.2 Install

1. Run the downloaded installer.
2. Accept all default options.
3. When prompted, allow installation of USB drivers, serial drivers, and device drivers.
4. Launch Arduino IDE when installation completes.

SCREENSHOT AI-01: Arduino IDE first launch. Capture the full IDE window showing the default empty sketch.

F2F2F2

## B.3 Install ESP32 Board Support

### B.3.1 Add Board Manager URL

5. In Arduino IDE, open: File → Preferences
6. Locate the field labeled: Additional Boards Manager URLs
7. Paste the following URL exactly:

https://raw.githubusercontent.com/espressif/arduino-esp32/gh-pages/package_esp32_index.json

8. Click OK.

### B.3.2 Install ESP32 Package

9. Open: Tools → Board → Boards Manager
10. In the search box, type: esp32
11. Locate: ESP32 by Espressif Systems
12. From the version dropdown, select: 2.0.17 (this is the version validated with this firmware)
13. Click Install.
14. Wait for installation to complete. This may take 5–15 minutes on a slower connection.

SCREENSHOT AI-02: File → Open menu sequence.

F2F2F2

SCREENSHOT AI-03: Boards Manager with 'esp32' in the search field.

F2F2F2

SCREENSHOT AI-04: ESP32 package installation page with version 2.0.17 selected and Install button.

F2F2F2

## B.4 Install Required Libraries

### B.4.1 Open Library Manager

Select: Sketch → Include Library → Manage Libraries

### B.4.2 NimBLE-Arduino

15. In the Library Manager search box, type: NimBLE-Arduino
16. Locate: NimBLE-Arduino by h2zero
17. Select version: 2.5.0
18. Click Install.

SCREENSHOT AI-05: Library Manager showing NimBLE-Arduino search result with version 2.5.0 selected.

F2F2F2

### B.4.3 Adafruit NeoPixel

19. In the Library Manager search box, type: Adafruit NeoPixel
20. Locate: Adafruit NeoPixel by Adafruit
21. Select version: 1.15.5
22. Click Install.
23. If prompted to install dependencies, click Install All.

SCREENSHOT AI-06: Library Manager showing Adafruit NeoPixel search result with version 1.15.5 selected.

F2F2F2

## B.5 Prepare the Firmware Project

### B.5.1 Required File Structure

Create a folder named exactly: BLE_TTP223_SWITCH_FUNCTION_STATE_MODEL

Place both firmware files inside this folder:

BLE_TTP223_SWITCH_FUNCTION_STATE_MODEL/

BLE_TTP223_SWITCH_FUNCTION_STATE_MODEL.ino

types.h

IMPORTANT: The folder name must exactly match the .ino filename.

IMPORTANT: Both files must be in the same folder. Do not rename either file.

### B.5.2 Open the Project

24. Launch Arduino IDE.
25. Select: File → Open
26. Navigate to the firmware folder and open: BLE_TTP223_SWITCH_FUNCTION_STATE_MODEL.ino
27. Arduino IDE will automatically open both the .ino file and types.h as separate tabs. This is normal and expected.

SCREENSHOT AI-02 (reference): File → Open menu. Show the menu open with Open highlighted.

F2F2F2

## B.6 Connect the ESP32

Connect the ESP32-S3 Supermini to the computer using a USB-C cable.

IMPORTANT: Many USB-C cables are charge-only and do not carry data.

If the device is not detected after connecting, try a different cable before troubleshooting further.

Data-capable cables are often labeled as such, or are included with devices like phones, tablets, or headphones.

## B.7 Select the Board

28. In Arduino IDE, open: Tools → Board → ESP32 Arduino
29. Select: ESP32S3 Dev Module

CRITICAL: You must select ESP32S3 Dev Module specifically.

Selecting any other board type will cause compilation or upload failures.

This selection is the most common source of first-time setup errors.

SCREENSHOT AI-07: Tools → Board menu showing ESP32S3 Dev Module highlighted and selected.

F2F2F2

## B.8 Select the COM Port

30. Open: Tools → Port
31. Select the port that appeared when you connected the ESP32.

Operating System | Expected Port Format | Example
Windows | COM followed by a number | COM5, COM8, COM12
macOS | Starts with /dev/cu.usbmodem | /dev/cu.usbmodem14201
Linux | Starts with /dev/ttyACM or /dev/ttyUSB | /dev/ttyACM0

If no port appears: replace the USB cable, reconnect the board, and restart Arduino IDE.

SCREENSHOT AI-08: Tools → Port menu showing a COM port selected.

F2F2F2

## B.9 Compile the Firmware

Before uploading, always compile first to check for errors.

32. Click the checkmark (✓) Verify button in the toolbar, or select: Sketch → Verify/Compile
33. Arduino IDE will check syntax, compile libraries, and build the firmware binary.
34. Expected result in the output panel: Done compiling.

SCREENSHOT AI-09: Verify button highlighted in the toolbar during compilation.

F2F2F2

SCREENSHOT AI-10: Output panel showing 'Done compiling.' with no errors.

F2F2F2

### B.9.1 Common Compilation Errors

Error Message | Cause | Resolution
NimBLEDevice.h: No such file or directory | NimBLE-Arduino library not installed | Install NimBLE-Arduino v2.5.0 via Library Manager
Adafruit_NeoPixel.h: No such file or directory | NeoPixel library not installed | Install Adafruit NeoPixel v1.15.5 via Library Manager
types.h: No such file or directory | types.h not in same folder as .ino | Move both files into the same named folder
Board not found / no ESP32 boards | ESP32 board package not installed | Install ESP32 by Espressif Systems v2.0.17

## B.10 Upload Firmware

35. Click the right-arrow (→) Upload button in the toolbar, or select: Sketch → Upload
36. Arduino IDE will compile, connect to the ESP32, erase flash, write firmware, and verify.
37. Typical upload time: 30–90 seconds.
38. Expected final message: Hard resetting via RTS pin...
39. Upload is complete when this message appears.

SCREENSHOT AI-11: Upload button highlighted in the toolbar.

F2F2F2

SCREENSHOT AI-12: Output panel showing 'Hard resetting via RTS pin...' indicating successful upload.

F2F2F2

### B.10.1 If Upload Fails — Manual Bootloader Entry

Some ESP32-S3 boards require manual entry into the bootloader before the first flash:

40. Hold the BOOT button on the ESP32 board.
41. While holding BOOT, briefly press and release the RESET button.
42. Release the BOOT button.
43. Immediately retry the Upload in Arduino IDE within 3 seconds.

This sequence puts the ESP32 into programming mode manually. It is only needed if automatic upload fails.

## B.11 Serial Monitor Verification

44. Open: Tools → Serial Monitor
45. Set the baud rate to: 115200
46. Press the RESET button on the ESP32.

Expected startup output:

=== SETUP START ===

=== PINS OK ===

=== NEOPIXEL OK ===

=== BLE INIT START ===

=== BLE DEVICE INIT OK ===

=== HID DEVICE CREATED ===

=== HID SERVICES STARTED ===

=== ADVERTISING STARTED ===

=== SETUP COMPLETE ===

All eight lines must appear. Any missing line indicates a firmware initialization failure.

SCREENSHOT AI-13: Serial Monitor at 115200 baud showing the full startup message sequence.

F2F2F2

# SECTION C — iPAD PAIRING AND SWITCH CONTROL CONFIGURATION

## C.1 Pair the Device

47. Power on the BLE Switch Node.
48. On the iPad, open: Settings → Bluetooth
49. Ensure Bluetooth is turned ON.
50. Under Other Devices, locate: BT Switch Node
51. Tap BT Switch Node to initiate pairing.
52. Accept any pairing confirmation prompts.
53. The device will move to the My Devices section showing Connected.

SCREENSHOT IP-01: Settings → Bluetooth showing the Bluetooth screen.

F2F2F2

SCREENSHOT IP-02: Bluetooth screen showing BT Switch Node visible under Other Devices.

F2F2F2

SCREENSHOT IP-03: Bluetooth screen showing BT Switch Node listed under My Devices with Connected status.

F2F2F2

After first pairing, the iPad and switch node will reconnect automatically on all future power-ups.

## C.2 Configure Switch Control

### C.2.1 Enable Switch Control

54. Open: Settings → Accessibility → Switch Control
55. Tap the Switch Control toggle to turn it ON.
56. The scanning cursor will appear on screen.

SCREENSHOT IP-04: Accessibility settings menu.

F2F2F2

SCREENSHOT IP-05: Switch Control settings screen with the master toggle.

F2F2F2

### C.2.2 Add Each Switch

57. Within Switch Control settings, tap: Switches → Add New Switch → External
58. When the prompt Activate the switch appears, touch the desired sensor or press the connected adaptive switch.
59. Enter a descriptive name for the switch (e.g., Left Touch, Right Switch).
60. Select the Switch Control action to assign (e.g., Select Item, Move to Next Item).
61. Tap Save.
62. Repeat for each input you wish to configure.

SCREENSHOT IP-06: Add New Switch screen.

F2F2F2

SCREENSHOT IP-07: External switch detection prompt.

F2F2F2

SCREENSHOT IP-08: Action assignment screen showing available Switch Control actions.

F2F2F2

SCREENSHOT IP-09: Completed switch list showing all configured inputs.

F2F2F2

## C.3 Verify Input Operation

With Bluetooth connected and Switch Control enabled, activate each input and observe the Serial Monitor:

Input Activated | Expected Serial Output | Expected iPad Action
Touch Sensor 1 | TOUCH 0 -> SHIFT+TAB | Move to previous item
Touch Sensor 2 | TOUCH 1 -> TAB | Move to next item
Touch Sensor 3 | TOUCH 2 -> ENTER | Select highlighted item
Switch Jack 1 | SWITCH 0 -> SHIFT+TAB | Move to previous item
Switch Jack 2 | SWITCH 1 -> TAB | Move to next item
Switch Jack 3 | SWITCH 2 -> ENTER | Select highlighted item

# SECTION D — TROUBLESHOOTING FLOWCHARTS AND ESCALATION

## D.1 Device Will Not Power On

Step | Check | If NO — Action | If YES — Action
1 | Connect USB-C cable to device and computer | Use a known-good data cable | Proceed to step 2
2 | Does any LED light appear? | Try a different USB port on the computer | Proceed to step 3
3 | LED still absent after two cables, two ports? | Replace ESP32-S3 Supermini board | Proceed to step 4
4 | Serial Monitor shows startup messages? | Reflash firmware per Section B | Device is functional — check BLE

## D.2 Device Will Not Upload (Flashing Failure)

Step | Check | If FAIL — Action | If PASS — Action
1 | Board set to ESP32S3 Dev Module? | Change board selection | Proceed to step 2
2 | Correct COM port selected? | Replug USB, refresh port list | Proceed to step 3
3 | Upload attempt — any error? | Try manual BOOT+RESET entry | Proceed to step 4
4 | Still failing after BOOT entry? | Reinstall ESP32 package v2.0.17 | Upload complete

## D.3 Bluetooth Will Not Connect

Step | Check | Negative Result — Action | Positive Result — Action
1 | Serial Monitor shows ADVERTISING STARTED? | Reflash firmware | Proceed to step 2
2 | BT Switch Node visible in iPad Bluetooth scan? | Reboot ESP32, rescan iPad | Proceed to step 3
3 | Pairing attempt succeeds? | Forget device on iPad, reboot ESP32, retry pair | Proceed to step 4
4 | iPad shows Connected? | Check Switch Control is enabled | Configure Switch Control

## D.4 Switch Inputs Not Registering

Symptom | First Check | Second Check | Escalate If
Touch sensor unresponsive | Serial Monitor for TOUCH messages | Re-seat TTP223 sensor wiring | No Serial output — replace TTP223
Adaptive switch unresponsive | Test switch with multimeter for continuity | Check 3.5 mm jack seating | No continuity — replace switch or cable
Input fires repeatedly | Check for debris on sensor surface | Check 35 ms debounce in firmware | Replace TTP223 if still erratic
Wrong action triggered | Verify Switch Control assignment | Re-assign action in Switch Control settings | Contact AT specialist

## D.5 Escalation Matrix

Issue Level | Who Handles | Response Time | Escalate To
Bluetooth reconnect failure | Teacher or paraeducator | Immediate — reboot device | Tech staff if unresolved in 5 min
Switch not registering | Teacher or paraeducator | Immediate — check cable | AT specialist if hardware related
Firmware reflash required | Technology staff | Same school day | District AT coordinator
Hardware damage / board failure | Technology staff | Same school day | Replacement unit dispatch
New device deployment | Technology staff | Per deployment schedule | District IT for inventory entry
Student evaluation change | AT specialist | Per IEP timeline | Special education director

# SECTION E — FORMAL ACCEPTANCE TESTING PROCEDURES

## E.1 Purpose

Every BLE Adaptive Switch Node unit must pass formal acceptance testing before being assigned to a student. This procedure verifies that the firmware is correct, all inputs function, and Bluetooth connectivity meets operational requirements.

## E.2 Pre-Deployment Acceptance Form

BLE ADAPTIVE SWITCH NODE — PRE-DEPLOYMENT ACCEPTANCE FORM

Complete one form per unit. Retain original in the technology department.

Attach a copy to the device checkout record.

Field | Entry
Device ID / Asset Number
Bluetooth Advertised Name
Firmware Version
ESP32 Chip ID (from Serial Monitor)
Date of Testing
Technician Name
Assigned Student / Room (if known)

### E.2.1 Hardware Checks

☐ Visual inspection — no physical damage, loose wiring, or cracked enclosure

☐ USB-C connector seated and functional

☐ All three TTP223 sensor modules present and attached

☐ All three 3.5 mm switch jacks present and undamaged

☐ NeoPixel LED present and not physically damaged

### E.2.2 Firmware and Startup Checks

☐ Device powers on — LED activates

☐ Serial Monitor at 115200 baud shows complete 8-line startup sequence

☐ ADVERTISING STARTED message confirmed

☐ Firmware version confirmed in Serial Monitor or source file

### E.2.3 Bluetooth Checks

☐ BT Switch Node (or custom name) visible in iPad Bluetooth scan

☐ Pairing completes without errors

☐ iPad shows Connected status

☐ Power-cycle reconnection test: power off device, power back on, iPad reconnects automatically within 10 seconds

### E.2.4 Input Verification — Touch Sensors

☐ Touch Sensor 1 activates — Serial Monitor shows TOUCH 0 -> SHIFT+TAB — LED turns Purple

☐ Touch Sensor 2 activates — Serial Monitor shows TOUCH 1 -> TAB — LED turns Red

☐ Touch Sensor 3 activates — Serial Monitor shows TOUCH 2 -> ENTER — LED turns Green

### E.2.5 Input Verification — Switch Jacks

☐ Switch Jack 1 activates with test switch — Serial Monitor shows SWITCH 0 -> SHIFT+TAB — LED turns Blue

☐ Switch Jack 2 activates — Serial Monitor shows SWITCH 1 -> TAB — LED turns Cyan

☐ Switch Jack 3 activates — Serial Monitor shows SWITCH 2 -> ENTER — LED turns Yellow

### E.2.6 Switch Control Integration Test

☐ Switch Control enabled on iPad

☐ All intended inputs assigned in Switch Control

☐ Switch Control scanning responds to touch inputs

☐ Switch Control scanning responds to adaptive switch inputs

☐ Selection action confirmed functional

### E.2.7 Final Result

Result | Technician Signature | Date
PASS / FAIL (circle one)

If FAIL: Document failure mode below and do not deploy unit until resolved.

Failure notes:

_____________________________________________________________________________

_____________________________________________________________________________

# SECTION F — ASSET MANAGEMENT

## F.1 Inventory Record Template

Maintain one row per physical device in the district inventory system. The master inventory may be kept in a spreadsheet, database, or district asset management platform.

Field | Description / Format
Asset Number | District-assigned unique identifier (e.g., AT-2024-001)
Bluetooth Name | Advertised BLE name programmed in firmware
Firmware Version | Version string from source file or Serial Monitor
Build Date | Date unit was assembled and flashed
Acceptance Test Date | Date of most recent acceptance test
Acceptance Test Result | PASS or FAIL
Current Building | Building name or code
Current Room | Room number
Assigned Staff | Teacher or AT specialist name
Assigned Student | Use student ID only — do not record student name in inventory
Last Inspection Date | Date of most recent monthly inspection
Next Inspection Due | Calculated 30 days from last inspection
Replacement Parts Date | Date of any hardware replacement (note what was replaced)
Decommission Date | Date unit was retired from service
Notes | Any relevant operational notes

## F.2 Device Checkout Form

Complete when any unit leaves the technology department or changes assignment.

DEVICE CHECKOUT FORM — BLE Adaptive Switch Node

Field | Entry
Asset Number
Bluetooth Name
Firmware Version
Checked Out To (Staff Name)
Building / Room
Student ID (if assigned)
Date Checked Out
Expected Return Date (if temporary)
Condition at Checkout (circle): | Good / Minor wear / Needs repair

Technology Staff Signature | Date

Receiving Staff Signature | Date

# SECTION G — TEACHER TRAINING HANDOUT

## G.1 Daily Startup Procedure

Complete the following every morning before student arrival:

1. | Power on the switch node using the USB-C cable or built-in battery switch.
2. | Wait 10 seconds for the device to initialize and begin advertising.
3. | On the student's iPad, open Settings → Bluetooth.
4. | Confirm BT Switch Node (or your unit's custom name) shows Connected.
5. | If not Connected, tap the device name to reconnect.
6. | Open Settings → Accessibility → Switch Control and confirm it is enabled.
7. | Test each switch the student uses with a brief activation — confirm the cursor moves.
8. | If Switch Control does not respond to a switch, see Section G.3 below.

## G.2 Daily Shutdown Procedure

63. Disconnect the switch node from the student's work area.
64. Visually inspect cables for any damage, kinking, or fraying.
65. Inspect switch jacks for secure seating — wiggle each adaptive switch cable gently.
66. Power off the device or leave connected to charge as per your building's protocol.
67. Store the device in its designated location — not in a drawer with sharp objects.

## G.3 Basic Troubleshooting (No Tech Required)

Switch stopped working mid-session:

Step 1: Check the Bluetooth status — Settings → Bluetooth → should show Connected.

Step 2: If Disconnected, tap the device name to reconnect.

Step 3: Check the physical cable between the adaptive switch and the device jack.

Step 4: Try a different switch jack on the device.

Step 5: If still not working, contact your AT specialist or technology staff.

Device disappeared from Bluetooth:

Step 1: Power off the switch node completely.

Step 2: Power it back on. Wait 15 seconds.

Step 3: On iPad, open Settings → Bluetooth — the device should reappear.

Step 4: Tap to reconnect.

Step 5: If it does not appear within 30 seconds, try forgetting the device and re-pairing.

## G.4 What to Report to Technology Staff

- Device will not power on after trying two different cables
- Bluetooth will not reconnect after repeated restarts
- One or more inputs never register in any test
- Physical damage to the enclosure, cables, or connectors
- NeoPixel LED is completely dark and does not illuminate on any input

# SECTION H — PARAEDUCATOR QUICK REFERENCE CARD

PRINT THIS PAGE AND KEEP IT WITH THE DEVICE.

Laminate for durability.

## Every Morning

☐ Power on the switch node

☐ iPad shows Connected next to the device name in Bluetooth settings

☐ Activate each switch once — the iPad cursor moves

## If a Switch Stops Working

Try This First | Then Try | Then Call
Check iPad Bluetooth — shows Connected? | Reboot device: power off, wait 10 sec, power on | AT specialist or technology staff
Wiggle the cable at the jack connector | Try a different jack on the device | Technology staff if hardware issue
Restart Switch Control: turn it OFF, wait 5 sec, turn ON | Forget and re-pair the device in Bluetooth settings | AT specialist if Switch Control issue

## If the Device Disappears from Bluetooth

68. Power off the switch node.
69. Wait 10 seconds.
70. Power it back on.
71. Open Settings → Bluetooth on the iPad.
72. The device name should reappear under Other Devices.
73. Tap to reconnect.

## LED Color Guide

LED Color | Which Input Was Activated
Purple | Touch Sensor 1
Red | Touch Sensor 2
Green | Touch Sensor 3
Blue | Switch Jack 1
Cyan | Switch Jack 2
Yellow | Switch Jack 3
Dark / Off | No input or no Bluetooth connection

## Who to Call

Situation | Contact
Bluetooth will not reconnect after restart | Technology Department
Switch not working — hardware suspected | Technology Department
Student's scanning pattern needs adjustment | AT Specialist
Switch Control actions need reconfiguring | AT Specialist or Teacher
Physical damage to device | Technology Department

# SECTION I — TECHNOLOGY DEPARTMENT MAINTENANCE PROCEDURES

## I.1 Monthly Maintenance Checklist

Complete for every active unit each calendar month. File completed checklists in the device folder.

Check Item | Pass | Fail — Notes
Confirm current firmware version matches district-approved version | ☐
Power on — complete startup sequence in Serial Monitor | ☐
Bluetooth advertisement visible from iPad scan | ☐
Pair or reconnect — iPad shows Connected | ☐
Touch Sensor 1 activates — correct Serial output and LED color | ☐
Touch Sensor 2 activates — correct Serial output and LED color | ☐
Touch Sensor 3 activates — correct Serial output and LED color | ☐
Switch Jack 1 activates — correct Serial output and LED color | ☐
Switch Jack 2 activates — correct Serial output and LED color | ☐
Switch Jack 3 activates — correct Serial output and LED color | ☐
Power-cycle reconnection test passes | ☐
Physical inspection — no damage | ☐

Technician Signature | Date

## I.2 Quarterly Maintenance

- Physical inspection of all units: enclosure integrity, connector condition, cable condition
- Full inventory audit: confirm physical count matches database records
- Confirm all units reflect the current district-approved firmware version
- Review any incident reports filed since the last quarterly review
- Update inventory records with current building/room/staff assignments

## I.3 Annual Maintenance

- Reflash all units with the then-current district-approved firmware
- Complete full acceptance test (Section E) on every unit after reflashing
- Update the change log (Section L) with annual firmware version
- Review and update all training materials if firmware behavior has changed
- Conduct full inventory audit and decommission any damaged or obsolete units

## I.4 Firmware Update Approval Form

Complete before deploying any new firmware version district-wide.

Field | Entry
New Firmware Version
Previous Firmware Version
Date of Change
Summary of Changes
Testing Completed By
Number of Units Tested
Pass Rate
Approved By (Technology Director)
Approved By (AT Coordinator)
Deployment Date

Technology Director Signature | Date

AT Coordinator Signature | Date

# SECTION J — AT SPECIALIST EVALUATION FORM

## J.1 Purpose

This form is completed by the Assistive Technology Specialist when evaluating a student's use of the BLE Adaptive Switch Node. It documents the student's current access method, performance metrics, and recommendations for the IEP team.

FERPA NOTICE: This form contains student-specific information. Store per district FERPA policies. Do not attach to or store with any device hardware.

## J.2 Student and Device Information

Field | Entry
Student ID (do not write name on device forms)
Evaluation Date
AT Specialist Name
IEP Meeting Date (if applicable)
Device Asset Number Used During Evaluation
Switch Configuration Evaluated

## J.3 Access Method Evaluation

### J.3.1 Current Access Method

☐ Capacitive Touch Sensors (TTP223)

☐ Adaptive Switches via 3.5 mm jack

☐ Combination of touch and adaptive switch

☐ Access method currently under evaluation — not yet determined

### J.3.2 Physical Positioning

Describe switch or sensor placement observed during evaluation:

_____________________________________________________________________________

_____________________________________________________________________________

### J.3.3 Accuracy

Metric | Observation
Correct activations per 10 attempts
Unintended activations per 10 attempts
Average time from intent to activation
Consistent activation force / contact? | Yes / No / Variable

### J.3.4 Fatigue

Metric | Observation
Duration of sustained use before fatigue signs
Observed fatigue indicators (describe)
Recommended maximum session length

### J.3.5 Student Response to LED Feedback

☐ Student notices and responds to LED color changes

☐ LED feedback does not appear to influence student behavior

☐ LED feedback is distracting — consider covering or disabling

## J.4 Recommendations

Switch configuration recommendation for IEP:

_____________________________________________________________________________

_____________________________________________________________________________

Positioning recommendation:

_____________________________________________________________________________

Training recommendation for staff:

_____________________________________________________________________________

Follow-up evaluation recommended: Yes / No If yes, within: ________ weeks

AT Specialist Signature | Date

# SECTION K — FERPA AND STUDENT PRIVACY GUIDANCE

## K.1 What FERPA Requires

The Family Educational Rights and Privacy Act (FERPA) prohibits the unauthorized disclosure of personally identifiable information from student education records. When deploying the BLE Adaptive Switch Node, technology staff and educators must follow the guidelines in this section.

## K.2 What Must NOT Be Stored on the Device

The ESP32-S3 Supermini has no non-volatile data storage accessible to the firmware beyond the program flash.

No student information of any kind is stored on or transmitted by the device firmware.

However, district staff must still comply with the following restrictions:

### K.2.1 Bluetooth Device Names Must Not Contain:

- Student full names or partial names
- Student ID numbers
- Any medical diagnosis or disability category
- Classroom identifiers that would allow identification of a specific student

COMPLIANT naming examples:

BT Switch Node B1-001

BT Switch Node Room 14A

Switch Node 07

NON-COMPLIANT naming examples:

BT Switch Node John Smith (contains student name)

Switch 042839 (contains student ID)

CP Switch Node Room 14 (contains disability category)

## K.3 Inventory Systems

- Inventory databases that link Asset Numbers to student identifiers must be stored in systems that comply with district FERPA data governance policies.
- Printed inventory sheets containing student ID assignments must be stored securely and not left in classrooms.
- Device labels must use asset numbers only, never student names.

## K.4 Evaluation Records

- AT specialist evaluation forms (Section J) contain student-identifiable information.
- These forms must be stored in the student's file per FERPA requirements.
- Do not photograph, scan, or transmit these forms through non-secure channels.
- Completed evaluation forms must not be left with the physical device or in unsecured classrooms.

## K.5 Questions

Contact your district FERPA compliance officer or special education director if you have questions about whether a specific practice complies with FERPA.

# SECTION L — MULTI-BUILDING DEPLOYMENT STANDARDS

## L.1 Device Naming Convention

When deploying multiple units across buildings, program a unique Bluetooth name into each unit's firmware before flashing. This prevents confusion when multiple devices are powered in the same space.

### L.1.1 Recommended Naming Format

Format: BT Switch Node [Building Code]-[Unit Number]

Examples:

BT Switch Node B1-001 (Building 1, Unit 001)

BT Switch Node B1-002 (Building 1, Unit 002)

BT Switch Node B2-001 (Building 2, Unit 001)

BT Switch Node ES-014 (Elementary School, Unit 014)

BT Switch Node MS-003 (Middle School, Unit 003)

### L.1.2 How to Change the Bluetooth Name

Before compiling firmware for a specific unit, locate this line in the .ino source file:

NimBLEDevice::init("BT Switch Node");

Change the name string to the unit's assigned name:

NimBLEDevice::init("BT Switch Node B1-001");

Compile and flash the firmware. Each unit will now advertise its unique name.

## L.2 Central Inventory Database

Maintain a single district-level inventory that tracks all units regardless of building. At minimum, include:

- Asset number
- Bluetooth name (must match what is programmed in firmware)
- Current building and room
- Current staff assignment
- Student ID assignment (secured per FERPA)
- Firmware version
- Last acceptance test date

## L.3 Cross-Building Transfer Procedure

When a unit moves from one building to another:

74. Update the inventory record with new building, room, and staff assignment.
75. Confirm the Bluetooth name is appropriate for the new location (rename in firmware if needed).
76. Complete a transfer inspection using the monthly checklist (Section I.1).
77. Notify the receiving building's AT specialist of the transfer.
78. Confirm the iPad in the new location can successfully pair or reconnect.

# SECTION M — CHANGE MANAGEMENT AND FIRMWARE VERSION CONTROL

## M.1 Firmware Version Log

Record every firmware version ever deployed district-wide. Never delete previous entries.

Version Number | Release Date | Approved By | Change Summary | Rollback Procedure
1.0.0 (initial) | | | Initial district deployment | N/A — first version

## M.2 Change Approval Process

79. Technology staff or AT coordinator identifies need for firmware change.
80. Proposed change is documented and tested on at least 2 units before broad deployment.
81. Technology Director and AT Coordinator review and sign the Firmware Update Approval Form (Section I.4).
82. Approved firmware is deployed to all units within the designated maintenance window.
83. All units are acceptance tested post-flash (abbreviated or full per supervisor direction).
84. Version log is updated.

## M.3 Rollback Procedure

If a new firmware version causes operational problems:

85. Locate the previous approved firmware source files in the district technology archive.
86. Flash all affected units with the previous version using the standard procedure (Section B).
87. Document the rollback in the firmware version log with date and reason.
88. Do not deploy the problem version to additional units until the issue is resolved.

ARCHIVE REQUIREMENT: All firmware source files for every version ever deployed must be retained

permanently. Store in district technology network storage, not only on individual computers.

Loss of a previous firmware version removes the ability to roll back.

# SECTION N — PRINTABLE APPENDICES

## Appendix A — Device Checkout Form

(See Section F.2 for the full form. Reproduce this page for daily use.)

Field | Entry
Asset Number
Bluetooth Name
Date Checked Out
Checked Out To
Building / Room
Student ID
Condition at Checkout | Good / Minor wear / Needs repair
Expected Return Date

Borrowing Staff Signature | Date

Technology Staff Signature | Date

## Appendix B — Classroom Daily Verification Form

Teacher or paraeducator completes daily. Keep with the device or in the classroom binder.

Date | Powered On | BT Connected | Switches Tested | Issue Noted | Initials
| ☐ | ☐ | ☐
| ☐ | ☐ | ☐
| ☐ | ☐ | ☐
| ☐ | ☐ | ☐
| ☐ | ☐ | ☐
| ☐ | ☐ | ☐
| ☐ | ☐ | ☐
| ☐ | ☐ | ☐
| ☐ | ☐ | ☐
| ☐ | ☐ | ☐

## Appendix C — Incident Report Form

Field | Entry
Asset Number
Date of Incident
Reported By (name and role)
Building / Room
Student ID (if involved)
Description of Incident
Immediate Action Taken
Follow-up Required? | Yes / No
Assigned To (for follow-up)
Resolution Date
Resolution Summary

Reporting Staff Signature | Date

Technology Staff Signature | Date

## Appendix D — Annual Inspection Form

Inspection Item | Pass | Fail — Notes
Enclosure — no cracks, loose parts, or sharp edges | ☐
USB-C connector functional for charging and data | ☐
All three TTP223 sensors present and responsive | ☐
All three 3.5 mm switch jacks present and functional | ☐
NeoPixel LED illuminates all colors correctly | ☐
Full startup sequence confirmed in Serial Monitor | ☐
Bluetooth advertising and pairing functional | ☐
All inputs verified with acceptance test (Section E) | ☐
Firmware version matches current approved version | ☐
Inventory record updated | ☐

Annual Inspection Technician | Date

Technology Director Approval | Date

## Appendix E — Firmware Update Approval Form

(See Section I.4 for the full form. Reproduce this page as needed.)

Field | Entry
New Firmware Version
Previous Firmware Version
Summary of Changes
Test Units Count
Test Pass Rate
Approved By — Technology Director
Approved By — AT Coordinator
Deployment Date
Rollback Instructions (attach or reference)

Technology Director Signature | Date

AT Coordinator Signature | Date

## Appendix F — AT Evaluation Worksheet (Abbreviated Field Copy)

(Full form in Section J. This is a condensed field copy for use during evaluation sessions.)

Field | Entry
Student ID
Evaluation Date
AT Specialist
Device Asset Number
Access Method Evaluated
Correct activations / 10 trials
Unintended activations / 10 trials
Fatigue threshold observed
Recommended switch configuration
Follow-up needed? | Yes / No Within: ___ weeks

AT Specialist Signature | Date

BLE Adaptive Switch Node — District Deployment Manual

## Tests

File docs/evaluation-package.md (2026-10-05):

---
layout: default
title: Switch Evaluation Package
permalink: /evaluation-package.html
---

# Adaptive Switch Assistive Technology Evaluation Package

*For Students with Cerebral Palsy and CVI / Visual Impairment*

*Developed by Michael Ryan Hunsaker, M.Ed., Ph.D. · Version of 2026-10-03*

<!-- web-only -->
**[Download the printable package (Word)](https://github.com/mrhunsaker/RB_SWITCH/raw/main/RB_Switch_Evaluation_Package.docx)**

This page holds the same content as `RB_Switch_Evaluation_Package.docx`, a fill-in package for evaluating, teaching, and documenting adaptive switch access. Use the Word file when you want to print the checklists and data sheets and fill them in by hand. The Word file is generated from this page (see [CONTRIBUTING](https://github.com/mrhunsaker/RB_SWITCH/blob/main/CONTRIBUTING.md)).

The package is general: it is not specific to the RB Switch, and it covers any switch, mount, or access site. It was written for evaluating students with cerebral palsy and cortical/cerebral visual impairment (CVI), but the stage-by-stage structure applies to other learners as well.

**Using the RB Switch in these trials**

The RB Switch has three small mechanical buttons: SW1 sends Left Arrow, SW2 sends Enter, and SW3 sends Right Arrow. How it fits each stage depends on the host device and app, so confirm the behavior in the actual app before you start collecting data.

| Package stage | How the RB Switch can be used |
|---|---|
| Stage 1 and 2: cause and effect, purposeful activation | Use any one button as the switch. Check that the app (or the Switch Control / Switch Access action you assign to the button) responds before collecting data. |
| Stage 3: single-switch scanning | Assign one button to **Select** and turn on auto scanning in iOS Switch Control or Android Switch Access. Record the scan speed on the data sheet. |
| Stage 4: two-switch step scanning | Use SW3 as **Next** (advance) and SW2 as **Select**. This is the two-switch setup Android's wizard supports. |
| Stage 5: multi-item and AAC | Use all three buttons: SW1 **Previous**, SW3 **Next**, SW2 **Select**. On Android, the third button is added after the wizard. |

Keep these limits in mind when you complete Section 4 (Motor & Access Site Assessment):

- The RB Switch buttons are small tactile buttons that need a deliberate press. It is one option among the switch types in Section 4.4 and does not replace large-plate, pillow, proximity, sip-and-puff, or other sensor switches for students who need them.
- It connects only by Bluetooth and has no jack for external switches.
- Record the RB Switch (and how it is mounted or positioned) as the switch type and placement on each data sheet.

Setup steps are in [Setup & Pairing]({{ '/setup.html' | relative_url }}), the host-side steps are in [Android Switch Access]({{ '/switch-access-android.html' | relative_url }}) and [iOS/iPadOS Switch Control]({{ '/switch-control-ios.html' | relative_url }}), and problems with the device itself are covered in [Troubleshooting]({{ '/troubleshooting.html' | relative_url }}). Appendix F of this package is a separate guide to *student performance* problems, not equipment faults.
<!-- /web-only -->

> **Note:** This package is an educational and clinical-practice resource. It does not replace individualized assessment, medical guidance, OT/PT positioning expertise, SLP/AAC assessment, TVI/CVI assessment, manufacturer instructions, or local educational requirements.

**Student & Evaluation Information**

| Field | Entry | Field | Entry |
| --- | --- | --- | --- |
| **Student Name** | | **Evaluator Name** | |
| **Date of Birth** | | **Title / Credentials** | |
| **Grade / Classroom Placement** | | **Evaluation Dates** | |
| **Diagnoses** | | **School / District** | |

**Assessments Completed**

| Stage | Date | Initials |
| --- | --- | --- |
| Stage 1 | | |
| Stage 2 | | |
| Stage 3 | | |
| Stage 4 | | |
| Stage 5 | | |

**3-Year Re-Evaluation**

| Due | Completed | Date |
| --- | --- | --- |
| | ☐ Yes ☐ No | |

<!-- pagebreak -->

## Table of Contents

- [SECTION 1: Background & Theoretical Framework](#section-1-background--theoretical-framework)
- [SECTION 2: Student Profile & Referral Information](#section-2-student-profile--referral-information)
- [SECTION 3: Pre-Assessment Observations Checklist](#section-3-pre-assessment-observations-checklist)
- [SECTION 4: Motor & Access Site Assessment](#section-4-motor--access-site-assessment)
- [SECTION 5: Visual & CVI Considerations for Switch Interface Design](#section-5-visual--cvi-considerations-for-switch-interface-design)
- [SECTION 6: Data Sheet — Stage 1: Cause-Effect Switch Activation](#section-6-data-sheet--stage-1-cause-effect-switch-activation)
- [SECTION 7: Data Sheet — Stage 2: Purposeful / Timed Switch Activation](#section-7-data-sheet--stage-2-purposeful--timed-switch-activation)
- [SECTION 8: Data Sheet — Stage 3: Single Switch App/Activity Access](#section-8-data-sheet--stage-3-single-switch-appactivity-access)
- [SECTION 9: Data Sheet — Stage 4: Two-Switch Step Scanning](#section-9-data-sheet--stage-4-two-switch-step-scanning)
- [SECTION 10: Data Sheet — Automatic vs. Manual Scanning Comparison](#section-10-data-sheet--automatic-vs-manual-scanning-comparison)
- [SECTION 11: Data Sheet — Stage 5: Multi-Item Selection & AAC Integration](#section-11-data-sheet--stage-5-multi-item-selection--aac-integration)
- [SECTION 12: Progress Tracking Summary & Graphing Sheet](#section-12-progress-tracking-summary--graphing-sheet)
- [SECTION 13: Assistive Technology Evaluation Summary Report](#section-13-assistive-technology-evaluation-summary-report)
- [APPENDIX A: Prompt Hierarchy Reference](#appendix-a-prompt-hierarchy-reference)
- [APPENDIX B: CVI Range-Aligned Interface Checklist](#appendix-b-cvi-range-aligned-interface-checklist)
- [APPENDIX C: Recommended Apps, Software & Resources](#appendix-c-recommended-apps-software--resources)
- [APPENDIX D: IEP Goal Writing Bank — Adaptive Switch Access](#appendix-d-iep-goal-writing-bank--adaptive-switch-access)
- [APPENDIX E: Implementation in Natural Settings](#appendix-e-implementation-in-natural-settings)
- [APPENDIX F: Troubleshooting Guide](#appendix-f-troubleshooting-guide)
- [APPENDIX G: Safety, Ethics, and Clinical Boundaries](#appendix-g-safety-ethics-and-clinical-boundaries)
- [References](#references)

<!-- pagebreak -->

## SECTION 1: Background & Theoretical Framework

### 1.1 What Are Adaptive Switches?

Adaptive switches are alternative access devices that allow individuals with physical, cognitive, and/or sensory disabilities to control technology without using standard touch or keyboard input. A switch is essentially a simple on/off interface—when activated (pressed, squeezed, blown into, moved toward, etc.), it sends a signal to a device, completing an action selected by scanning software or cause-effect applications.

For students with cerebral palsy (CP) and cortical/cerebral visual impairment (CVI), adaptive switches can unlock access to communication, learning, play, and environmental control that would otherwise be inaccessible.

The switch itself is not the intervention; it is the access mechanism that connects the person's response to a meaningful activity or outcome.

#### The Access Chain

Effective switch access can be understood as a chain with six linked components:

1. **Person** — the individual's motor, sensory, visual, cognitive, communication, and motivational characteristics.
2. **Response** — a voluntary movement or other observable action the person can perform with useful reliability.
3. **Switch** — the sensor or interface that detects the response without requiring unnecessary force, range, speed, or precision.
4. **Mounting and positioning** — the physical relationship among the person, switch, seating system, and activity.
5. **Interface or software** — the system that interprets the switch signal through cause-effect, timed activation, scanning, selection, AAC, or computer access.
6. **Outcome** — a meaningful consequence such as communication, social interaction, preferred stimulation, learning, play, environmental control, or task completion.

> **Important — Training principle:** If performance is poor, do not assume the student needs more prompting. Examine every link in the access chain before increasing assistance.

#### Switch Use vs. Switch Access

A student can physically press a switch without demonstrating functional switch use. Functional access requires a relationship between the response, the timing of the response, the selected target, and the meaningful outcome. Intentionality—not simple physical activation—determines readiness to advance through the stages.

#### Continuum of Switch Use: From Cause-Effect to Multi-Item Scanning

> **Important — Key Principle:** The progression from cause-effect to scanning is NOT linear in a strict developmental sense—it is an instructional sequence shaped by cognitive readiness, motor access, and visual processing. Students should move to the next level when they demonstrate consistent intentionality, NOT simply when they can physically activate a switch. A student may require one stage for one activity while using a more advanced method for another.

The instructional hierarchy for switch access typically proceeds through five stages:

- **Stage 1 – Cause and Effect:** Student activates a switch and experiences a contingent outcome (sound, light, movement). Goal is understanding that their action creates change in the environment.
- **Stage 2 – Purposeful Activation:** Student activates a switch at specific moments (e.g., to turn music on/off, answer yes/no, operate a toy). There is a clear communicative or operational intent.
- **Stage 3 – Single Switch Scanning:** An on-screen cursor or highlight moves through items automatically (auto-scan) or with a 'next' switch press (step scan). The student activates the switch to select the highlighted item.
- **Stage 4 – Two-Switch Scanning:** One switch advances the scan; a second switch selects. This approach reduces accidental selections and allows finer control. Students develop the ability to wait, anticipate, and time their selections.
- **Stage 5 – Multiple Switch / Directed Scanning:** Multiple switches navigate in multiple directions (up, down, left, right, select). Used for complex grids, AAC systems, and computer control.

| Stage | Primary skill | Typical access arrangement | Primary evidence of learning |
| --- | --- | --- | --- |
| 1. Cause and effect | Action produces a predictable consequence | One switch + contingent stimulus | Repeated independent activations tied to the outcome |
| 2. Purposeful/timed activation | Action occurs at a meaningful moment | One switch + structured opportunity | Timing and communicative/operational intent |
| 3. Single-switch scanning | One switch selects among sequential choices | Auto-scan or step scan | Accurate selection of targets |
| 4. Two-switch scanning | Separate advance and select responses | Two switches | Deliberate navigation and selection |
| 5. Multi-item/AAC integration | Navigation, selection, and message construction | Multiple switches or scanning | Functional communication/control across contexts |

#### Why Students with CP and CVI Require Special Consideration

Cerebral palsy affects motor control in ways that range from minor coordination difficulties to complete absence of voluntary limb movement. Students may have spasticity, athetosis, ataxia, or mixed types, each affecting the precision, timing, and consistency of switch activation differently. CP can also affect tone, range of motion, motor planning, timing, strength, coordination, endurance, and movement consistency—so switch selection must be individualized to the student's specific presentation. A site-by-site motor assessment is essential before any switch trials.

Cortical/Cerebral Visual Impairment (CVI) is a neurological condition affecting how the brain processes visual information. It is the leading cause of visual impairment in children in developed countries and frequently co-occurs with CP due to shared neurological etiology. CVI manifests along a spectrum (Roman-Lantzy CVI Range: Phase I–III) and profoundly affects:

- Color preference (high-contrast, single colors may be required)
- Visual field preferences (lateral, lower, or central depending on phase)
- Need for movement to attract and sustain visual attention
- Visual latency (delayed processing—student may not respond immediately)
- Complexity tolerance (clutter, backgrounds, and competing visual stimuli impair access)
- Distance vision and near vision variability

These visual processing characteristics directly affect switch interface design—apps, overlays, scanning highlights, icon size, contrast, and background must be calibrated to the student's CVI phase.

Visual impairment—including blindness—does not automatically prevent switch use. It changes how the evaluator should establish orientation to the task, feedback, target presentation, auditory cues, and scanning.

### 1.2 Evidence Base

The use of switch-based assistive technology is supported by a robust evidence base across multiple disciplines:

- **HAAT model:** Switch access framed within the Human Activity Assistive Technology model, emphasizing that technology efficacy depends on alignment between the student's abilities, the activity demands, and the assistive technology context.
- **Microswitch research:** Demonstrated that even micro-switch responses can establish meaningful communication and environmental control for students with the most profound disabilities.
- **CVI Range:** Provides a standardized observational instrument for measuring CVI characteristics and guides environmental modifications directly applicable to switch interface design.
- **SETT Framework:** Student-Environment-Tasks-Tools—the gold standard for AT evaluation, requiring assessment of student needs in the context of their specific environments and tasks before selecting tools.
- **QIAT:** Provides standards for AT evaluation, implementation, and follow-up in educational settings.
- **AAC research:** Demonstrates that switch-based access is a viable and effective pathway to augmentative communication for students with complex communication needs.

These sources are complementary rather than interchangeable: SETT and HAAT organize feature matching and context; QIAT addresses service delivery; CVI assessment informs visual access; AAC research addresses communication outcomes; and microswitch studies provide examples of people with severe or profound disabilities learning to control meaningful environmental or social events.

#### Microswitch Research with Blind or Visually Impaired Participants

| Year | Study | Population / visual status | Microswitch function | Training relevance |
| --- | --- | --- | --- | --- |
| 2004 | A computer system serving as a microswitch for vocal utterances of persons with multiple disabilities: Two case evaluations | Persons with multiple disabilities (published in *Journal of Visual Impairment & Blindness*) | Computer-based detection of vocal utterances functioned as microswitch-like access | Switch access need not be a mechanical button; alternative response modalities are viable |
| 2005–2006 | An optic micro-switch for an eyelid response to foster environmental control in children with minimal motor behaviour | Children with profound multiple disabilities and minimal motor behavior | Optic sensor on eyeglass frame detected marked eyelid/eye-opening movement and activated preferred stimulation | Extremely small responses can be made functional when detection is engineered around the available movement |
| 2005 | Further evaluation of microswitch clusters to enhance hand response and head control in persons with multiple disabilities | Participants with profound intellectual disabilities, spastic tetraparesis, and visual impairment | Pressure microswitch for adaptive hand response combined with a position microswitch for head position | Multiple switch conditions can support both engagement and postural goals |
| 2006 | A microswitch-based program to enable students with multiple disabilities to choose among environmental stimuli | Students with severe/profound disability and motor and visual impairment | Two microswitches linked to computer-presented preferred/nonpreferred stimulus choices | Directly relevant to choice-making, preference assessment, and two-response access |
| 2007 | Enabling students with multiple disabilities to request and choose among environmental stimuli through microswitch and computer technology | Students with multiple disabilities | Two basic microswitches triggered presentation of stimulus samples | Model for teaching choice, requesting, and contingent access |
| 2008 | Enabling two persons with multiple disabilities to access environmental stimuli and ask for social contact through microswitches and a VOCA | Participants with multiple disabilities; one nearly totally blind with profound intellectual and motor disabilities | Two microswitches provided direct access to preferred stimuli; VOCA provided caregiver contact | Strong example of combining environmental control and social communication |
| 2008 | Three persons with multiple disabilities accessing environmental stimuli and asking for social contact through microswitch and VOCA technology | Three participants with multiple disabilities | Two microswitches for environmental stimuli plus VOCA for social contact | Supports combining switch-based environmental control with communication rather than treating them as competing systems |
| 2009 | Persons with multiple disabilities access stimulation and contact the caregiver via microswitch and VOCA technology | Eight children/adolescents with combined intellectual, motor, and visual disabilities | Microswitch for direct access to selected environmental stimuli plus VOCA for caregiver contact | Relevant to integrated access and generalization across response forms |
| 2014 | Microswitch-aided programs to support physical exercise or adequate ambulation in persons with multiple disabilities | Study I involved a woman with blindness and severe intellectual and motor disabilities who used a wheelchair | Microswitch-aided program delivered preferred stimulation contingent on head and arm/hand movements | Microswitch contingencies can be designed around posture and physical activity, not only communication or toy control |

Related research also includes people with blindness or severe visual impairment using computer-aided telephone systems, indoor-navigation systems, and other technology-aided programs. These studies support the broader principle of accessible technology but should not be cited as direct evidence that a particular mechanical switch or scanning configuration is effective.

> **Warning — Evidence limitation:** Most microswitch research is based on small samples and single-case or case-series designs. It is highly useful for demonstrating feasibility and functional relationships in individuals with complex disabilities, but it does not establish a universal switch type, scan speed, or success rate for all students.

### 1.3 Functional Outcomes

Switch access should ultimately serve functional outcomes such as:

- Requesting preferred objects, activities, people, or repetitions
- Rejecting, stopping, or protesting an activity
- Answering yes/no questions
- Selecting between two or more options
- Accessing music, videos, toys, lights, vibration, or other preferred stimulation
- Operating environmental controls when appropriate and safely configured
- Participating in AAC through scanning
- Accessing computer or tablet functions
- Increasing active engagement in educational, recreational, social, or occupational activities

<!-- pagebreak -->

## SECTION 2: Student Profile & Referral Information

| Field | Entry |
| --- | --- |
| **Student Name** | |
| **DOB** | |
| **Evaluator** | |
| **Date** | |

### 2.1 Diagnostic Summary

| Item | Response |
| --- | --- |
| **CP Type** | ☐ Spastic ☐ Dyskinetic/Athetoid ☐ Ataxic ☐ Mixed ☐ Unknown |
| **CP Topography** | ☐ Hemiplegia ☐ Diplegia ☐ Quadriplegia ☐ Monoplegia |
| **GMFCS Level** | ☐ I ☐ II ☐ III ☐ IV ☐ V |
| **MACS Level** | ☐ I ☐ II ☐ III ☐ IV ☐ V |
| **CVI Diagnosis** | ☐ Yes ☐ No ☐ Suspected but not formally diagnosed |
| **CVI Phase (if known)** | ☐ Phase I (0–3) ☐ Phase II (4–7) ☐ Phase III (8–10) Score: _______ |
| **Additional Diagnoses** | |
| **Seizure Disorder** | ☐ Yes (last seizure: __________) ☐ No ☐ Controlled with medication |
| **Cognitive Level (estimated)** | ☐ Age-appropriate ☐ Mild ID ☐ Moderate ID ☐ Severe ID ☐ Profound ID |
| **Communication Status** | ☐ Verbal ☐ Functional AAC user ☐ Emerging AAC ☐ Pre-symbolic |

### 2.2 Prior AT History

Describe any previous switch access or AT device trials, including outcome:

_______________________________________________________________________________________

_______________________________________________________________________________________

_______________________________________________________________________________________

### 2.3 Current Educational Placement & Goals

Setting: ☐ General Ed with supports ☐ Resource ☐ SDC ☐ NPS ☐ Home/Hospital

IEP Goals related to AT / Communication / Access:

_______________________________________________________________________________________

_______________________________________________________________________________________

_______________________________________________________________________________________

### 2.4 Referral Reason

☐ New evaluation — no prior switch use

☐ Re-evaluation — existing switch user, determine advancement

☐ Transition to new device/platform

☐ Regression or plateau in switch use

☐ AAC system change requiring new access method

☐ Other: ______________________________________________________________________________

### 2.5 SETT Framework Application

Apply the SETT framework before selecting tools. Define the student by functional characteristics, not diagnosis or GMFCS/MACS level alone.

**Student** — Document the student's motor repertoire, voluntary movement, tone, range, endurance, communication, cognition, sensory profile, vision, hearing, visual latency, preferences, and typical patterns of initiation.

**Environment** — Identify where switch access must work: classroom, therapy, cafeteria, playground, home, community, transportation, and other relevant environments. Record seating systems, table height, device location, lighting, noise, people moving behind the display, caregiver availability, and device-management demands.

**Tasks** — Specify the real activity. "Use switch" is not a functional task. Examples include "request continuation of a song," "select a preferred story," "answer yes/no during a classroom routine," "call caregiver," or "select a word in AAC."

**Tools** — Select the least complex tool that provides reliable access to the required task. Consider switch type, activation force, travel, sensitivity, mounting, cable routing, connector, interface, scan mode, scan speed, feedback, and durability.

<!-- pagebreak -->

## SECTION 3: Pre-Assessment Observations Checklist

| Field | Entry |
| --- | --- |
| **Student** | |
| **Observer** | |
| **Setting** | |
| **Date** | |

Complete this checklist across at least 2 natural settings before formal switch trials begin. These observations establish a functional baseline and inform switch type, placement, and interface design. Observing in natural settings ensures the student's posture, motivation, fatigue, and communication behavior are representative.
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

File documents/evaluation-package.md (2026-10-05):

---
layout: default
title: Switch Evaluation Package
---

# Adaptive Switch Assistive Technology Evaluation Package

*For Students with Cerebral Palsy and CVI / Visual Impairment*

*Developed by Michael Ryan Hunsaker, M.Ed., Ph.D. · Version of 2026-10-03*

<!-- web-only -->
**[Download the printable package (Word)](https://github.com/mrhunsaker/RB_SWITCH/raw/main/RB_Switch_Evaluation_Package.docx)**

This page holds the same content as `RB_Switch_Evaluation_Package.docx`, a fill-in package for evaluating, teaching, and documenting adaptive switch access. Use the Word file when you want to print the checklists and data sheets and fill them in by hand. The Word file is generated from this page (see [CONTRIBUTING](https://github.com/mrhunsaker/RB_SWITCH/blob/main/CONTRIBUTING.md)).

The package is general: it is not specific to the RB Switch, and it covers any switch, mount, or access site. It was written for evaluating students with cerebral palsy and cortical/cerebral visual impairment (CVI), but the stage-by-stage structure applies to other learners as well.

**Using the RB Switch in these trials**

The RB Switch has three small mechanical buttons: SW1 sends Left Arrow, SW2 sends Enter, and SW3 sends Right Arrow. How it fits each stage depends on the host device and app, so confirm the behavior in the actual app before you start collecting data.

| Package stage | How the RB Switch can be used |
|---|---|
| Stage 1 and 2: cause and effect, purposeful activation | Use any one button as the switch. Check that the app (or the Switch Control / Switch Access action you assign to the button) responds before collecting data. |
| Stage 3: single-switch scanning | Assign one button to **Select** and turn on auto scanning in iOS Switch Control or Android Switch Access. Record the scan speed on the data sheet. |
| Stage 4: two-switch step scanning | Use SW3 as **Next** (advance) and SW2 as **Select**. This is the two-switch setup Android's wizard supports. |
| Stage 5: multi-item and AAC | Use all three buttons: SW1 **Previous**, SW3 **Next**, SW2 **Select**. On Android, the third button is added after the wizard. |

Keep these limits in mind when you complete Section 4 (Motor & Access Site Assessment):

- The RB Switch buttons are small tactile buttons that need a deliberate press. It is one option among the switch types in Section 4.4 and does not replace large-plate, pillow, proximity, sip-and-puff, or other sensor switches for students who need them.
- It connects only by Bluetooth and has no jack for external switches.
- Record the RB Switch (and how it is mounted or positioned) as the switch type and placement on each data sheet.

Setup steps are in [Setup & Pairing](setup.md), the host-side steps are in [Android Switch Access](switch-access-android.md) and [iOS/iPadOS Switch Control](switch-control-ios.md), and problems with the device itself are covered in [Troubleshooting](troubleshooting.md). Appendix F of this package is a separate guide to *student performance* problems, not equipment faults.
<!-- /web-only -->

> **Note:** This package is an educational and clinical-practice resource. It does not replace individualized assessment, medical guidance, OT/PT positioning expertise, SLP/AAC assessment, TVI/CVI assessment, manufacturer instructions, or local educational requirements.

**Student & Evaluation Information**

| Field | Entry | Field | Entry |
| --- | --- | --- | --- |
| **Student Name** | | **Evaluator Name** | |
| **Date of Birth** | | **Title / Credentials** | |
| **Grade / Classroom Placement** | | **Evaluation Dates** | |
| **Diagnoses** | | **School / District** | |

**Assessments Completed**

| Stage | Date | Initials |
| --- | --- | --- |
| Stage 1 | | |
| Stage 2 | | |
| Stage 3 | | |
| Stage 4 | | |
| Stage 5 | | |

**3-Year Re-Evaluation**

| Due | Completed | Date |
| --- | --- | --- |
| | ☐ Yes ☐ No | |

<!-- pagebreak -->

## Table of Contents

- [SECTION 1: Background & Theoretical Framework](#section-1-background--theoretical-framework)
- [SECTION 2: Student Profile & Referral Information](#section-2-student-profile--referral-information)
- [SECTION 3: Pre-Assessment Observations Checklist](#section-3-pre-assessment-observations-checklist)
- [SECTION 4: Motor & Access Site Assessment](#section-4-motor--access-site-assessment)
- [SECTION 5: Visual & CVI Considerations for Switch Interface Design](#section-5-visual--cvi-considerations-for-switch-interface-design)
- [SECTION 6: Data Sheet — Stage 1: Cause-Effect Switch Activation](#section-6-data-sheet--stage-1-cause-effect-switch-activation)
- [SECTION 7: Data Sheet — Stage 2: Purposeful / Timed Switch Activation](#section-7-data-sheet--stage-2-purposeful--timed-switch-activation)
- [SECTION 8: Data Sheet — Stage 3: Single Switch App/Activity Access](#section-8-data-sheet--stage-3-single-switch-appactivity-access)
- [SECTION 9: Data Sheet — Stage 4: Two-Switch Step Scanning](#section-9-data-sheet--stage-4-two-switch-step-scanning)
- [SECTION 10: Data Sheet — Automatic vs. Manual Scanning Comparison](#section-10-data-sheet--automatic-vs-manual-scanning-comparison)
- [SECTION 11: Data Sheet — Stage 5: Multi-Item Selection & AAC Integration](#section-11-data-sheet--stage-5-multi-item-selection--aac-integration)
- [SECTION 12: Progress Tracking Summary & Graphing Sheet](#section-12-progress-tracking-summary--graphing-sheet)
- [SECTION 13: Assistive Technology Evaluation Summary Report](#section-13-assistive-technology-evaluation-summary-report)
- [APPENDIX A: Prompt Hierarchy Reference](#appendix-a-prompt-hierarchy-reference)
- [APPENDIX B: CVI Range-Aligned Interface Checklist](#appendix-b-cvi-range-aligned-interface-checklist)
- [APPENDIX C: Recommended Apps, Software & Resources](#appendix-c-recommended-apps-software--resources)
- [APPENDIX D: IEP Goal Writing Bank — Adaptive Switch Access](#appendix-d-iep-goal-writing-bank--adaptive-switch-access)
- [APPENDIX E: Implementation in Natural Settings](#appendix-e-implementation-in-natural-settings)
- [APPENDIX F: Troubleshooting Guide](#appendix-f-troubleshooting-guide)
- [APPENDIX G: Safety, Ethics, and Clinical Boundaries](#appendix-g-safety-ethics-and-clinical-boundaries)
- [References](#references)

<!-- pagebreak -->

## SECTION 1: Background & Theoretical Framework

### 1.1 What Are Adaptive Switches?

Adaptive switches are alternative access devices that allow individuals with physical, cognitive, and/or sensory disabilities to control technology without using standard touch or keyboard input. A switch is essentially a simple on/off interface—when activated (pressed, squeezed, blown into, moved toward, etc.), it sends a signal to a device, completing an action selected by scanning software or cause-effect applications.

For students with cerebral palsy (CP) and cortical/cerebral visual impairment (CVI), adaptive switches can unlock access to communication, learning, play, and environmental control that would otherwise be inaccessible.

The switch itself is not the intervention; it is the access mechanism that connects the person's response to a meaningful activity or outcome.

#### The Access Chain

Effective switch access can be understood as a chain with six linked components:

1. **Person** — the individual's motor, sensory, visual, cognitive, communication, and motivational characteristics.
2. **Response** — a voluntary movement or other observable action the person can perform with useful reliability.
3. **Switch** — the sensor or interface that detects the response without requiring unnecessary force, range, speed, or precision.
4. **Mounting and positioning** — the physical relationship among the person, switch, seating system, and activity.
5. **Interface or software** — the system that interprets the switch signal through cause-effect, timed activation, scanning, selection, AAC, or computer access.
6. **Outcome** — a meaningful consequence such as communication, social interaction, preferred stimulation, learning, play, environmental control, or task completion.

> **Important — Training principle:** If performance is poor, do not assume the student needs more prompting. Examine every link in the access chain before increasing assistance.

#### Switch Use vs. Switch Access

A student can physically press a switch without demonstrating functional switch use. Functional access requires a relationship between the response, the timing of the response, the selected target, and the meaningful outcome. Intentionality—not simple physical activation—determines readiness to advance through the stages.

#### Continuum of Switch Use: From Cause-Effect to Multi-Item Scanning

> **Important — Key Principle:** The progression from cause-effect to scanning is NOT linear in a strict developmental sense—it is an instructional sequence shaped by cognitive readiness, motor access, and visual processing. Students should move to the next level when they demonstrate consistent intentionality, NOT simply when they can physically activate a switch. A student may require one stage for one activity while using a more advanced method for another.

The instructional hierarchy for switch access typically proceeds through five stages:

- **Stage 1 – Cause and Effect:** Student activates a switch and experiences a contingent outcome (sound, light, movement). Goal is understanding that their action creates change in the environment.
- **Stage 2 – Purposeful Activation:** Student activates a switch at specific moments (e.g., to turn music on/off, answer yes/no, operate a toy). There is a clear communicative or operational intent.
- **Stage 3 – Single Switch Scanning:** An on-screen cursor or highlight moves through items automatically (auto-scan) or with a 'next' switch press (step scan). The student activates the switch to select the highlighted item.
- **Stage 4 – Two-Switch Scanning:** One switch advances the scan; a second switch selects. This approach reduces accidental selections and allows finer control. Students develop the ability to wait, anticipate, and time their selections.
- **Stage 5 – Multiple Switch / Directed Scanning:** Multiple switches navigate in multiple directions (up, down, left, right, select). Used for complex grids, AAC systems, and computer control.

| Stage | Primary skill | Typical access arrangement | Primary evidence of learning |
| --- | --- | --- | --- |
| 1. Cause and effect | Action produces a predictable consequence | One switch + contingent stimulus | Repeated independent activations tied to the outcome |
| 2. Purposeful/timed activation | Action occurs at a meaningful moment | One switch + structured opportunity | Timing and communicative/operational intent |
| 3. Single-switch scanning | One switch selects among sequential choices | Auto-scan or step scan | Accurate selection of targets |
| 4. Two-switch scanning | Separate advance and select responses | Two switches | Deliberate navigation and selection |
| 5. Multi-item/AAC integration | Navigation, selection, and message construction | Multiple switches or scanning | Functional communication/control across contexts |

#### Why Students with CP and CVI Require Special Consideration

Cerebral palsy affects motor control in ways that range from minor coordination difficulties to complete absence of voluntary limb movement. Students may have spasticity, athetosis, ataxia, or mixed types, each affecting the precision, timing, and consistency of switch activation differently. CP can also affect tone, range of motion, motor planning, timing, strength, coordination, endurance, and movement consistency—so switch selection must be individualized to the student's specific presentation. A site-by-site motor assessment is essential before any switch trials.

Cortical/Cerebral Visual Impairment (CVI) is a neurological condition affecting how the brain processes visual information. It is the leading cause of visual impairment in children in developed countries and frequently co-occurs with CP due to shared neurological etiology. CVI manifests along a spectrum (Roman-Lantzy CVI Range: Phase I–III) and profoundly affects:

- Color preference (high-contrast, single colors may be required)
- Visual field preferences (lateral, lower, or central depending on phase)
- Need for movement to attract and sustain visual attention
- Visual latency (delayed processing—student may not respond immediately)
- Complexity tolerance (clutter, backgrounds, and competing visual stimuli impair access)
- Distance vision and near vision variability

These visual processing characteristics directly affect switch interface design—apps, overlays, scanning highlights, icon size, contrast, and background must be calibrated to the student's CVI phase.

Visual impairment—including blindness—does not automatically prevent switch use. It changes how the evaluator should establish orientation to the task, feedback, target presentation, auditory cues, and scanning.

### 1.2 Evidence Base

The use of switch-based assistive technology is supported by a robust evidence base across multiple disciplines:

- **HAAT model:** Switch access framed within the Human Activity Assistive Technology model, emphasizing that technology efficacy depends on alignment between the student's abilities, the activity demands, and the assistive technology context.
- **Microswitch research:** Demonstrated that even micro-switch responses can establish meaningful communication and environmental control for students with the most profound disabilities.
- **CVI Range:** Provides a standardized observational instrument for measuring CVI characteristics and guides environmental modifications directly applicable to switch interface design.
- **SETT Framework:** Student-Environment-Tasks-Tools—the gold standard for AT evaluation, requiring assessment of student needs in the context of their specific environments and tasks before selecting tools.
- **QIAT:** Provides standards for AT evaluation, implementation, and follow-up in educational settings.
- **AAC research:** Demonstrates that switch-based access is a viable and effective pathway to augmentative communication for students with complex communication needs.

These sources are complementary rather than interchangeable: SETT and HAAT organize feature matching and context; QIAT addresses service delivery; CVI assessment informs visual access; AAC research addresses communication outcomes; and microswitch studies provide examples of people with severe or profound disabilities learning to control meaningful environmental or social events.
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

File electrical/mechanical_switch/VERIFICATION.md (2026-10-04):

# RB Switch PCB verification

Date: 2026-10-03. Files checked: `RB_Switch.kicad_sch`, `RB_Switch.kicad_pcb`, `net_table.json` in this folder, against `firmware/RB_SWITCH_firmware/RB_SWITCH_firmware.ino`.

These checks were run with scripts that read the KiCad files directly. KiCad itself was **not** run for this verification, so KiCad's own ERC and DRC remain the authority. The most recent KiCad reports supplied for this design showed no clearance, short, or unconnected-pin errors; the remaining messages were library and field-parity items that have since been addressed.

## 1. Does the board work as a three-button BLE keyboard?

| Check | Result |
|---|---|
| SW1 net goes to U1 pin 14 (IO10); firmware reads GPIO10 | Pass |
| SW2 net goes to U1 pin 15 (IO11); firmware reads GPIO11 | Pass |
| SW3 net goes to U1 pin 16 (IO12); firmware reads GPIO12 | Pass |
| Each switch's other side goes to ground, so a press pulls the input LOW (matches `INPUT_PULLUP`, active LOW) | Pass |
| Switch footprint: the two pads on the top edge form the switch net and the two pads on the bottom edge are ground, so the switch contacts sit between the net and ground (not shorted at rest). Assumes the standard B3F arrangement where the two pads on each edge are one terminal. | Pass |
| GPIO10–12 are not strapping pins (strapping pins are GPIO0, 3, 45, 46) | Pass |
| 100 nF filter capacitor (C9–C11) from each switch net to ground | Pass |
| USB D+ goes to U1 pin 24 (IO20) and D− to pin 23 (IO19), both from the USB-C pads | Pass |
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

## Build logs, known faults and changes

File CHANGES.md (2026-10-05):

# Changelog

All notable changes to this project are documented in this file.

The format is based on [Keep a Changelog](https://keepachangelog.com/en/1.1.0/). This project does not currently follow strict semantic versioning for hardware/firmware releases; entries are grouped by date instead.

## [Unreleased]

### Hardware (2026-10-03)

- **Schematic rewritten with real wires.** Every connection is now drawn pin to pin, with power symbols for GND, 3V3, VBAT and VBUS and net labels on the 15 signal nets. Previously the file had only short stubs ending in labels.
- **PCB re-routed and re-placed.** All 19 named nets are routed on F.Cu/B.Cu with GND (In1) and 3V3 (In2) planes. SW1–SW3, the two M4 holes and J_USB stay at their original positions; the other parts were moved to give the tracks room.
- **USB D+ / D− corrected.** D+ (A6/B6) now goes to U1 pin 24 (IO20) and D− (A7/B7) to pin 23 (IO19). They were swapped.
- **REG1 FB (pin 10) now connected to the 3.3 V output.** It was floating.
- **REG1 footprint is now `Package_SON:Texas_DRC0010J`** (no thermal-via pads). Four GND vias sit in the exposed pad.
- **Schematic and PCB parity.** Net names, reference designators, values, descriptions, datasheets and footprint links match. `J_BAT`, `J_USB`, `SW_BOOT`, `SW_RST`, `U_CHG` are now `J_BAT1`, `J_USB1`, `SW_BOOT1`, `SW_RST1`, `U_CHG1`. The 34 unused pins have `unconnected-(...)` nets. MH1/MH2 are marked "Not in schematic".
- **SW1–SW3 footprint link** is now `Button_Switch_THT:SW_TH_Tactile_Omron_B3F-100x`. L1's schematic footprint now matches the PCB (`L_Bourns-SRN4018`), and its pads were checked against the Bourns SRN4018 recommended layout.
- **Project rule:** minimum hole clearance lowered from 0.25 mm to 0.15 mm because of the J_USB1 footprint.
- **Added C12, 1 µF from EN to ground**, forming an RC reset delay with R5 (10 kΩ). C12 is an 0603 at (183.2, 113.6) on the front side, routed to R5 pad 2 with a ground via. BOM (C4, C12 are now a pair of 1 µF), CPL, net table and docs updated.
- `electrical/mechanical_switch/VERIFICATION.md` added. `net_table.json`, the layout and schematic previews, and the CPL/BOM workbooks in `bom/` were regenerated or updated for the new design.
- **Not yet regenerated:** `electrical/mechanical_switch/gerbers/` and the PCB images in `electrical/mechanical_switch/diagrams/` are from an earlier layout. Re-export with `create_gerber.ps1` before ordering.

### Switch Evaluation Package (2026-10-05)

- **New page: Switch Evaluation Package** (`docs/evaluation-package.md`, `documents/evaluation-package.md`), published at `/evaluation-package.html`. It is the *Adaptive Switch Assistive Technology Evaluation Package* by Michael Ryan Hunsaker, M.Ed., Ph.D.: background and evidence base, student profile and SETT framework, observation checklists, motor and CVI assessment, five stage data sheets, a scanning comparison, progress graphing, summary report and signature page, and seven appendices (prompt hierarchy, CVI interface checklist, apps, IEP goal bank, natural-settings implementation, performance troubleshooting, safety and ethics).
- **New download: `RB_Switch_Evaluation_Package.docx`**, a 49-page printable version generated from the page. The data sheets are in landscape. It is built the same way as the paraprofessional setup guide.
- The web page adds a short, web-only note on using the RB Switch in the trials (which buttons to use at each stage, and its limits as a small-button switch). It is not part of the Word file.
- **Changes to the source text:** the Markdown was converted for the website (alert boxes became labelled callouts, the contents list became a manual list with links, the cover-sheet "Assessments Completed" lines became a table) and two typos were fixed: "APPENCIDES" is now "APPENDICES" and "palmer grasp" is now "palmar grasp". A stray empty bullet in Appendix E was removed.
- **`tools/build_docx.js` replaces `tools/build_setup_docx.js`.** It builds both Word documents (or one, with `setup` or `evaluation`) and adds landscape sections, colored callouts, handwriting lines, minimum column widths and taller rows in fill-in tables. `tools/README.md` documents the Markdown comments that control the output.
- README, `docs/index.md`, `docs/qr-code.md`, CONTRIBUTING and `tools/README.md` updated to list the new page and download.

### Documentation polish (2026-10-03)

- **README rewritten.** Adds an at-a-glance table, quick start, firmware build steps, a troubleshooting summary, a documentation-by-audience table, a repository layout table and the pre-order checklist.
- **Troubleshooting page rewritten** (`docs/troubleshooting.md`, `documents/troubleshooting.md`). It now has a symptom table, a description of normal behavior, Bluetooth and pairing, buttons, iOS/Android, power and charging, firmware upload and Serial Monitor, board-level checks with expected voltages, switch input checks, and what to include when asking for help.
- **Setup guide completed** (`docs/setup.md`, `documents/setup.md` and `RB_Switch_Paraprofessional_Setup_Guide.docx`). Adds an at-a-glance table, an expanded troubleshooting table, charging-light meanings, a daily checklist, a "Getting help" section and firmware prerequisites. The printable guide is now generated from `docs/setup.md`.
- **Corrected the Bluetooth name.** The docs said the switch advertises as "RB Switch" plus a 3-digit number matching a sticker. The firmware advertises plain "RB Switch" on every unit. The docs now say so and explain how to tell units apart.
- **Documented firmware behavior** that was not written down before: presses are ignored while disconnected, there is no power switch or sleep mode, battery level is fixed at 100%, bonding needs no passkey, and the sketch needs NimBLE-Arduino 2.x.
- Fixed broken section links in `docs/firmware-customization.md` and `docs/switch-access-android.md`. Added a printing guide and the published URL to `docs/qr-code.md`, and a "Which page do I need?" table to `docs/index.md`.
- **New `tools/` folder:** `sync_documents.py` rewrites `documents/` from `docs/`, and `build_docx.js` rebuilds the printable Word documents from `docs/`.

### Documentation and firmware (2026-10-03)

- `docs/hardware.md` and `documents/hardware.md` rewritten: pin map, part-by-part connections, PCB summary, library notes and a pre-order checklist.
- `docs/firmware.md`, `docs/troubleshooting.md` and `docs/firmware-customization.md` (and their `documents/` copies) updated: native USB / **USB CDC On Boot** note, bootloader procedure, GPIO5 battery sense and other pins in use.
- `README.md` points to the verification report and the pre-order note.
- `firmware/RB_SWITCH_firmware/RB_SWITCH_firmware.ino`: header comments now list every U1 connection on the board. **No behaviour change.**
- `bom/RB_SWITCH_RevD_SOURCING_NOTES.md` updated for the new designators, footprints and CPL.

### Added

- `docs/switch-access-android.md` and `documents/switch-access-android.md` — a dedicated walkthrough for Android Switch Access, covering the Google Play Store install step and how to assign a third (Previous) switch outside the guided setup wizard.
- `docs/switch-control-ios.md` and `documents/switch-control-ios.md` — a dedicated walkthrough for iOS/iPadOS Switch Control, for contrast with the Android flow.
- `docs/firmware-customization.md` and `documents/firmware-customization.md` — a guide to safely modifying `RB_SWITCH_firmware.ino` (key remapping, debounce timing, device naming, and a HID Usage ID reference table).
- `CONTRIBUTING.md`, `CODE_OF_CONDUCT.md`, `SECURITY.md`, `CODE_STYLE.md`, `LICENSE`.
- `.github/ISSUE_TEMPLATE/` (bug report, hardware issue, documentation issue, feature request) and `.github/PULL_REQUEST_TEMPLATE.md`.
- `.github/CODEOWNERS`.

### Changed

- `docs/setup.md` and `documents/setup.md` rewritten to clearly separate Android (Switch Access) and iOS/iPadOS (Switch Control) setup, including the Android-specific one-switch/two-switch wizard limitation and the Play Store install requirement.
- `docs/index.md`, `documents/index.md`, `docs/use.md`, `documents/use.md`, `docs/firmware.md`, `documents/firmware.md` updated with cross-links to the new pages.
- `docs/troubleshooting.md` and `documents/troubleshooting.md` gained entries for the Android two-switch wizard limitation and for Switch Access not appearing until installed from the Play Store.
- `README.md` updated to reference the new documentation pages and community files.

## 2026-09-27 — Production documentation baseline

This is the state of the project as of the initial GitHub Pages publication, prior to the documentation overhaul above.

### Added

- Production firmware: `firmware/RB_SWITCH_firmware/RB_SWITCH_firmware.ino` — three-button BLE HID keyboard (Left Arrow / Enter / Right Arrow) on the RevD/RevD2 mechanical-switch PCB.
- Hardware sources for the RevD/RevD2 PCB (`electrical/`), enclosure (`mechanical/`), and bill of materials (`bom/`).
- GitHub Pages documentation (`docs/`) and a packaging-friendly mirror (`documents/`): Setup & Pairing, Switch Operation, Firmware, Hardware, Troubleshooting, and QR Code pages.
- `RB_Switch_Paraprofessional_Setup_Guide.docx`, a printable classroom quick-reference.
- GitHub Actions workflow (`.github/workflows/static.yml`) to build and publish `docs/` with Jekyll.

### Notes

- An earlier, 11-input adaptive-switch prototype (`firmware/BLE_ADAPTIVE_SWITCH_EXPANDED_SCAFFOLD/`) was marked archived; it is retained for historical reference only and is not part of the current production scope.

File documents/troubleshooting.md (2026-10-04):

---
layout: default
title: Troubleshooting
---

# Troubleshooting

Use this page when the RB Switch does not behave as described in [Setup & Pairing](setup.md) and [Switch Operation](use.md). Sections 1–5 are for classroom staff. Sections 6–8 are for technicians who can program the board or open the enclosure.

## Start here

| Symptom | Most likely cause | Go to |
|---|---|---|
| RB Switch is not in the Bluetooth list | No power, flat battery, or connected to another device | [Section 1](#1-bluetooth-and-pairing) |
| Listed but will not connect, or pairs then drops | Stale pairing, range, or low battery | [Section 1](#1-bluetooth-and-pairing) |
| Connected, but a button does nothing | Connection lost, or a switch fault | [Section 2](#2-buttons) |
| One button works differently or not at all | Switch fault or host setting | [Section 2](#2-buttons) |
| Only two buttons work on Android | Third switch not assigned | [Section 3](#3-accessibility-features-ios-and-android) |
| Works in a text box, not in Switch Control/Access | Accessibility not set up | [Section 3](#3-accessibility-features-ios-and-android) |
| Will not power on, or battery drains quickly | Flat battery, cable, or no sleep mode | [Section 4](#4-power-charging-and-the-light) |
| Charging light behaves oddly | Normal charger behavior | [Section 4](#4-power-charging-and-the-light) |
| Firmware upload fails or no serial port | Cable or download mode | [Section 5](#5-firmware-upload-and-serial-monitor) |
| Board dead or a voltage is wrong | Hardware fault | [Section 6](#6-board-level-checks-for-technicians) |

## How the RB Switch behaves (so you know what is normal)

- It advertises as **RB Switch** as soon as it has power. The name is the same on every unit.
- There is **no power switch and no sleep mode**. It runs whenever USB-C or the battery is connected.
- It reports a fixed battery level of 100%. The host's battery indicator for the RB Switch does not change.
- A button press made while it is not connected is **dropped**. It is not sent later.
- Each press sends one key press and one key release about 20 ms later. Holding a button does not repeat the key.
- Inputs are debounced for 35 ms.
- After a disconnect, it starts advertising again automatically.
- The charge light (D1) belongs to the charger. The firmware does not control it.

## 1. Bluetooth and pairing

### RB Switch does not appear in Bluetooth

1. Confirm the RB Switch has power. Plug in USB-C for a few minutes in case the battery is flat.
2. Move it within about 3 feet of the device.
3. Turn Bluetooth off and on again on the device and refresh the list.
4. Check whether another device (a phone, tablet, or computer that was paired before) is already connected. A connected host stops the RB Switch from showing up elsewhere. Turn Bluetooth off on the other devices, or choose Forget on them.
5. If it was previously paired, remove/forget the old pairing and pair again.
6. Restart the RB Switch (technicians: press RESET, or disconnect and reconnect power).

### It is listed but will not connect, or connects and then drops

1. Forget RB Switch on the device and pair again.
2. Charge the battery from USB-C for at least an hour.
3. Move away from sources of interference such as routers, microwaves, USB 3 hubs, and many other Bluetooth devices.
4. Try a different host device. If it pairs with a different device, the problem is the first device's Bluetooth stack. Restart that device.
5. If it still fails, the RB Switch's stored pairing data may be out of step with the host. See [Clearing the RB Switch's stored pairings](#clearing-the-rb-switchs-stored-pairings).

### Clearing the RB Switch's stored pairings

The firmware enables bonding, so the RB Switch stores pairing information in flash memory. If a host forgot the RB Switch but the RB Switch still holds the old pairing (or the reverse), the two can refuse to reconnect.

1. Forget RB Switch on the host device.
2. In the Arduino IDE, set **Tools → Erase All Flash Before Sketch Upload** to **Enabled**.
3. Upload the production firmware again.
4. Set that option back to **Disabled** so later uploads do not erase settings.
5. Pair again from the host.

### Two RB Switches in one room

Both advertise as "RB Switch". Pair one at a time with the other unplugged or out of range. To tell units apart permanently, give each a different name in the firmware (see [Firmware Customization](firmware-customization.md)).

## 2. Buttons

### Connected, but a button does nothing

1. Confirm RB Switch shows **Connected** in Bluetooth settings. Presses made while disconnected are lost.
2. Press all three buttons in a plain text field.
   - SW1 → Left Arrow
   - SW2 → Enter
   - SW3 → Right Arrow
3. If all three fail, disconnect and reconnect, then try a different host.
4. If only one fails, the problem is probably that switch, its solder joints, or its trace. See [Section 7](#7-switch-input-checks).
5. If the buttons work in a text field but not in an accessibility feature, see [Section 3](#3-accessibility-features-ios-and-android).

### A button repeats, double-presses, or fires by itself

The firmware sends one press and one release when a button changes from released to pressed, with 35 ms debounce, so a held button should not repeat.

- Check the host first: iOS **Switch Stabilization** and **Ignore Repeat**, Android Switch Access timing, and any host "key repeat" setting.
- If a student's motor pattern causes extra presses, raise `DEBOUNCE_MS` in small steps (50–75 ms). See [Firmware Customization](firmware-customization.md).
- If it happens without anyone touching it, inspect the switch, solder joints, the 100 nF capacitor on that input, the ground connection, and the PCB for damage, flux, or moisture.

### The wrong key is sent

The mapping is fixed in the firmware: SW1 Left Arrow, SW2 Enter, SW3 Right Arrow. If a different key arrives, the unit may be running modified firmware. Re-upload the production firmware from `firmware/RB_SWITCH_firmware/`.

## 3. Accessibility features (iOS and Android)

### Works in a text field but not in Switch Control or Switch Access

- Confirm the feature is turned on.
- Confirm each RB Switch button was added as an external switch and assigned an action.
- Re-add the switch and press the requested RB Switch button when the device asks.
- Note: the RB Switch sends Left Arrow, Enter, and Right Arrow to any app, whether or not scanning is on. In an app that also responds to arrow keys, this can look like scanning works when it does not.

### Only two of three buttons do anything in Android Switch Access

This is expected, not a fault. Android's setup wizard only asks for one or two switches. Assign the third under **Settings → Accessibility → Switch Access → Settings → Assign switches for scanning**. See [Android Switch Access](switch-access-android.md).

### Switch Access does not appear on an Android device

Switch Access is a separate app on the **Google Play Store**. Install or update it, open it once, then check **Settings → Accessibility** again.

### A button opens a menu or does something unexpected

Left Arrow, Enter, and Right Arrow are ordinary keys. Another shortcut or app on the device may also react to them. Check the device's keyboard-shortcut settings and the switch assignments.

## 4. Power, charging, and the light

### The RB Switch will not power on

1. Plug in a known-good USB-C power source and data-capable cable for at least 30 minutes.
2. Try a different charger. Some USB-C to USB-C chargers only supply power if the device presents the correct resistors on its CC pins. This board has them (R3 and R4, 5.1 kΩ), so a charger that does not work with it may be faulty.
3. Check that the battery connector is seated and the battery is not damaged or swollen. If it is swollen, stop using it.
4. Technicians: continue with [Section 6](#6-board-level-checks-for-technicians).

### Charging light (D1)

D1 is controlled by the MCP73831 charger. It is not a status light for Bluetooth or buttons.

- **On:** the battery is charging from USB-C.
- **Off:** charging is complete, or USB-C is not connected.
- The charger and the RB Switch share the battery. While the RB Switch is plugged in and running, the charger may not reach its end-of-charge point as quickly, and the light may stay on longer than you expect. This is normal.

### The battery runs down quickly

The RB Switch has no sleep mode and no power switch. It uses power whenever it is connected to a battery. Recharge regularly. For long storage, trained staff can disconnect the battery connector. The firmware reports a fixed 100% battery level, so a host's battery reading cannot be used to judge charge.

### Battery safety

Before connecting or replacing a battery:

- Verify connector polarity. Pin 1 of the JST-PH connector (J_BAT1) is the positive terminal.
- Verify nominal cell voltage (single-cell Li-Po, 3.7 V nominal, 4.2 V full).
- Verify appropriate battery protection.
- Verify physical fit.
- Verify compatibility with the MCP73831 charging circuit (about 500 mA charge current).

A JST-PH connector alone does not guarantee compatible polarity. Stop using any battery that is hot, swollen, or damaged.

## 5. Firmware upload and Serial Monitor

### USB powers the board but firmware upload fails

1. Use a known data-capable USB-C cable. Many charge-only cables look identical.
2. Enter the ESP32-S3 bootloader: hold **BOOT**, press and release **RESET**, then release **BOOT**. Retry the upload.
3. In the Arduino IDE, confirm the board is **ESP32S3 Dev Module** and the correct port is selected.
4. Close any other program that has the serial port open (such as another Serial Monitor).
5. If the sketch does not compile, confirm you have the NimBLE-Arduino library, version 2.x. The sketch uses the 2.x callback signatures.

### No serial port appears

The board has no USB-to-serial chip. It uses the ESP32-S3's native USB.

1. Enter the bootloader as above. A port should appear while it is in download mode.
2. Try a different cable and a different USB port.
3. If a port still does not appear, check the USB lines in [Section 6](#6-board-level-checks-for-technicians).

### Serial Monitor shows nothing

In the Arduino IDE, set **Tools → USB CDC On Boot** to **Enabled**, re-upload, and reopen the Serial Monitor at **115200** baud. After a reset, the port may disappear and reappear, so reselect it if needed.

### What the Serial Monitor should show

At startup:

```
RB Switch firmware
SW1 GPIO10 -> Left Arrow
SW2 GPIO11 -> Enter
SW3 GPIO12 -> Right Arrow
BLE advertising as "RB Switch"
```

When a host connects: `BLE connected`. When one disconnects: `BLE disconnected; restarting advertising`. A button press prints `SW GPIOxx -> HID 0xYY`, or `Key ignored: BLE not connected` if no host is connected.

## 6. Board-level checks for technicians

Do these only with the battery disconnected unless the step says otherwise, and with ESD precautions. Use a multimeter. The PCB layout and net names are in [Hardware](hardware.md) and `electrical/mechanical_switch/`.

| Check | Where | Expected | If wrong |
|---|---|---|---|
| Battery voltage | J_BAT1 pin 1 (+) to pin 2 (−) | 3.0–4.2 V, pin 1 positive | Wrong polarity or flat/damaged cell |
| 3.3 V rail | C2 or C3, across the capacitor, battery connected | 3.3 V (±5%) | See below |
| VBUS from USB-C | C4, USB-C plugged in | About 5 V | Cable, charger, or J_USB1 solder joints |
| CC resistors | R3 (CC1) and R4 (CC2) to ground, power off | About 5.1 kΩ each | Without these, USB-C chargers may not supply power |
| Charge current set | R1 (PROG) to ground | 2 kΩ | Wrong value changes charge current |
| EN (reset) | U1 pin 45, or C12 | About 3.3 V idle, 0 V while RESET is pressed | Stuck low: SW_RST1 or C12 shorted. Stuck high: SW_RST1 open |
| IO0 (boot) | R6 / SW_BOOT1 net, U1 pin 4 | About 3.3 V idle, 0 V while BOOT is pressed | Stuck low forces download mode on every start |
| Battery sense | R7/R8 midpoint, battery connected | Half the battery voltage (for example 2.0 V at 4.0 V) | R7, R8, or C8 fault. The firmware does not read this input yet |
| USB data | J_USB1 D+ pads to U1 pin 24; D− pads to U1 pin 23 (continuity, power off) | Continuity | Open or shorted USB trace |

### 3.3 V rail is missing or wrong

1. With the battery connected, measure VBAT at C1. If it is near 0 V, the battery or connector is the problem.
2. If VBAT is good but 3.3 V is absent, measure resistance from the 3.3 V rail to ground with power off. Near 0 Ω means a shorted capacitor (C2, C3, C5, C6, C7, or C12) or a short at U1.
3. Check REG1 (TPS63001) for solder bridges, especially the exposed pad, and check L1 for a good joint on both pads.
4. REG1 enable is tied to VBAT, so it starts as soon as the battery is present.

### Board runs hot or resets under load

A hot battery, regulator, or charger is a fault. Disconnect the battery. Look for solder bridges near REG1, U_CHG1, and J_BAT1. Confirm the battery is a single-cell Li-Po rated for the load.

## 7. Switch input checks

Each of SW1, SW2, and SW3 connects its input to ground when pressed. Idle level is high, from the ESP32's internal pull-up.

1. With the board running, measure the input at the switch pad that is not ground. It should read about 3.3 V idle and about 0 V while pressed. Use a high-impedance meter, because the internal pull-up is weak.
2. With power off, check continuity across the switch contacts while pressing. It should close only when pressed.
3. No change when pressed: check the switch solder joints and the trace.
4. Reads 0 V all the time: look for a short across the 100 nF capacitor (C9, C10, or C11) on that input, or solder bridging at the switch.

| Switch | Net | U1 pin | GPIO |
|---|---|---|---|
| SW1 | `/SW1_NET` | 14 | GPIO10 |
| SW2 | `/SW2_NET` | 15 | GPIO11 |
| SW3 | `/SW3_NET` | 16 | GPIO12 |

## 8. When to ask for help

When you report a problem, include:

- The device type and operating-system version.
- Which button or action is affected.
- Whether it happens in a plain text field.
- Whether the charging light is on and whether the unit runs from USB or battery.
- The Serial Monitor output if you have it.
- What you have already tried.

For firmware or hardware issues, use the [Firmware](firmware.md) and [Hardware](hardware.md) pages and the source files. Use the repository's issue templates for bug and hardware reports.

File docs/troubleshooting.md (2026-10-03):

---
layout: default
title: Troubleshooting
permalink: /troubleshooting.html
---

# Troubleshooting

## RB Switch does not appear in Bluetooth

1. Confirm the RB Switch is powered.
2. Power-cycle the RB Switch.
3. Wait several seconds.
4. Search for **RB Switch** again.
5. If it was previously paired, remove/forget the old pairing and pair again.

## RB Switch is connected but a button does nothing

Test all three buttons:

- SW1 → Left Arrow
- SW2 → Enter
- SW3 → Right Arrow

If only one button fails, the problem may be isolated to that switch or input circuit.

If the buttons work in a normal text field but not in an accessibility feature, check the host's Switch Control or Switch Access configuration.

## Only two of three buttons do anything in Android Switch Access

This is expected behavior, not a fault. Android's Switch Access setup wizard only ever asks for **one or two** switches; a third switch (Previous) must be assigned separately under **Settings → Accessibility → Switch Access → Settings → Assign switches for scanning**. See [Android Switch Access]({{ '/switch-access-android.html' | relative_url }}) for the full walkthrough. This does not affect iOS/iPadOS, Windows, macOS, Linux, or Chromebook, where all three buttons work through their normal setup flow.

## Switch Access doesn't appear on an Android device at all

Switch Access is distributed as a standalone app on the **Google Play Store**, separate from Android Accessibility Suite. Install or update it from the Play Store, then check **Settings → Accessibility** again. See [Android Switch Access]({{ '/switch-access-android.html' | relative_url }}).

## Button repeats unexpectedly

The production firmware sends one key press/release when a button changes from released to pressed and uses 35 ms debounce. A held button should not repeat.

If it does, inspect the switch, solder joints, input capacitor, ground connection, and PCB for damage or contamination.

## USB powers the board but firmware upload fails

Use a known data-capable USB-C cable. If necessary, hold BOOT, press and release RESET, then release BOOT to enter the ESP32-S3 bootloader and retry.

## Serial Monitor shows nothing

The board uses the ESP32-S3's native USB rather than a USB-to-serial chip. In the Arduino IDE, set **Tools → USB CDC On Boot** to **Enabled**, re-upload, and reopen the Serial Monitor at 115200 baud.

## Charging LED

D1 is controlled by the MCP73831 charger, not the BLE firmware. It lights while the battery is charging from USB.

## Battery

Before connecting or replacing a battery:

- Verify connector polarity.
- Verify nominal cell voltage.
- Verify appropriate battery protection.
- Verify physical fit.
- Verify compatibility with the MCP73831 charging circuit.

A JST-PH connector alone does not guarantee compatible polarity.

## Technical support

For firmware or hardware issues, use the [Firmware](firmware.html) and [Hardware](hardware.html) pages and the production source files.

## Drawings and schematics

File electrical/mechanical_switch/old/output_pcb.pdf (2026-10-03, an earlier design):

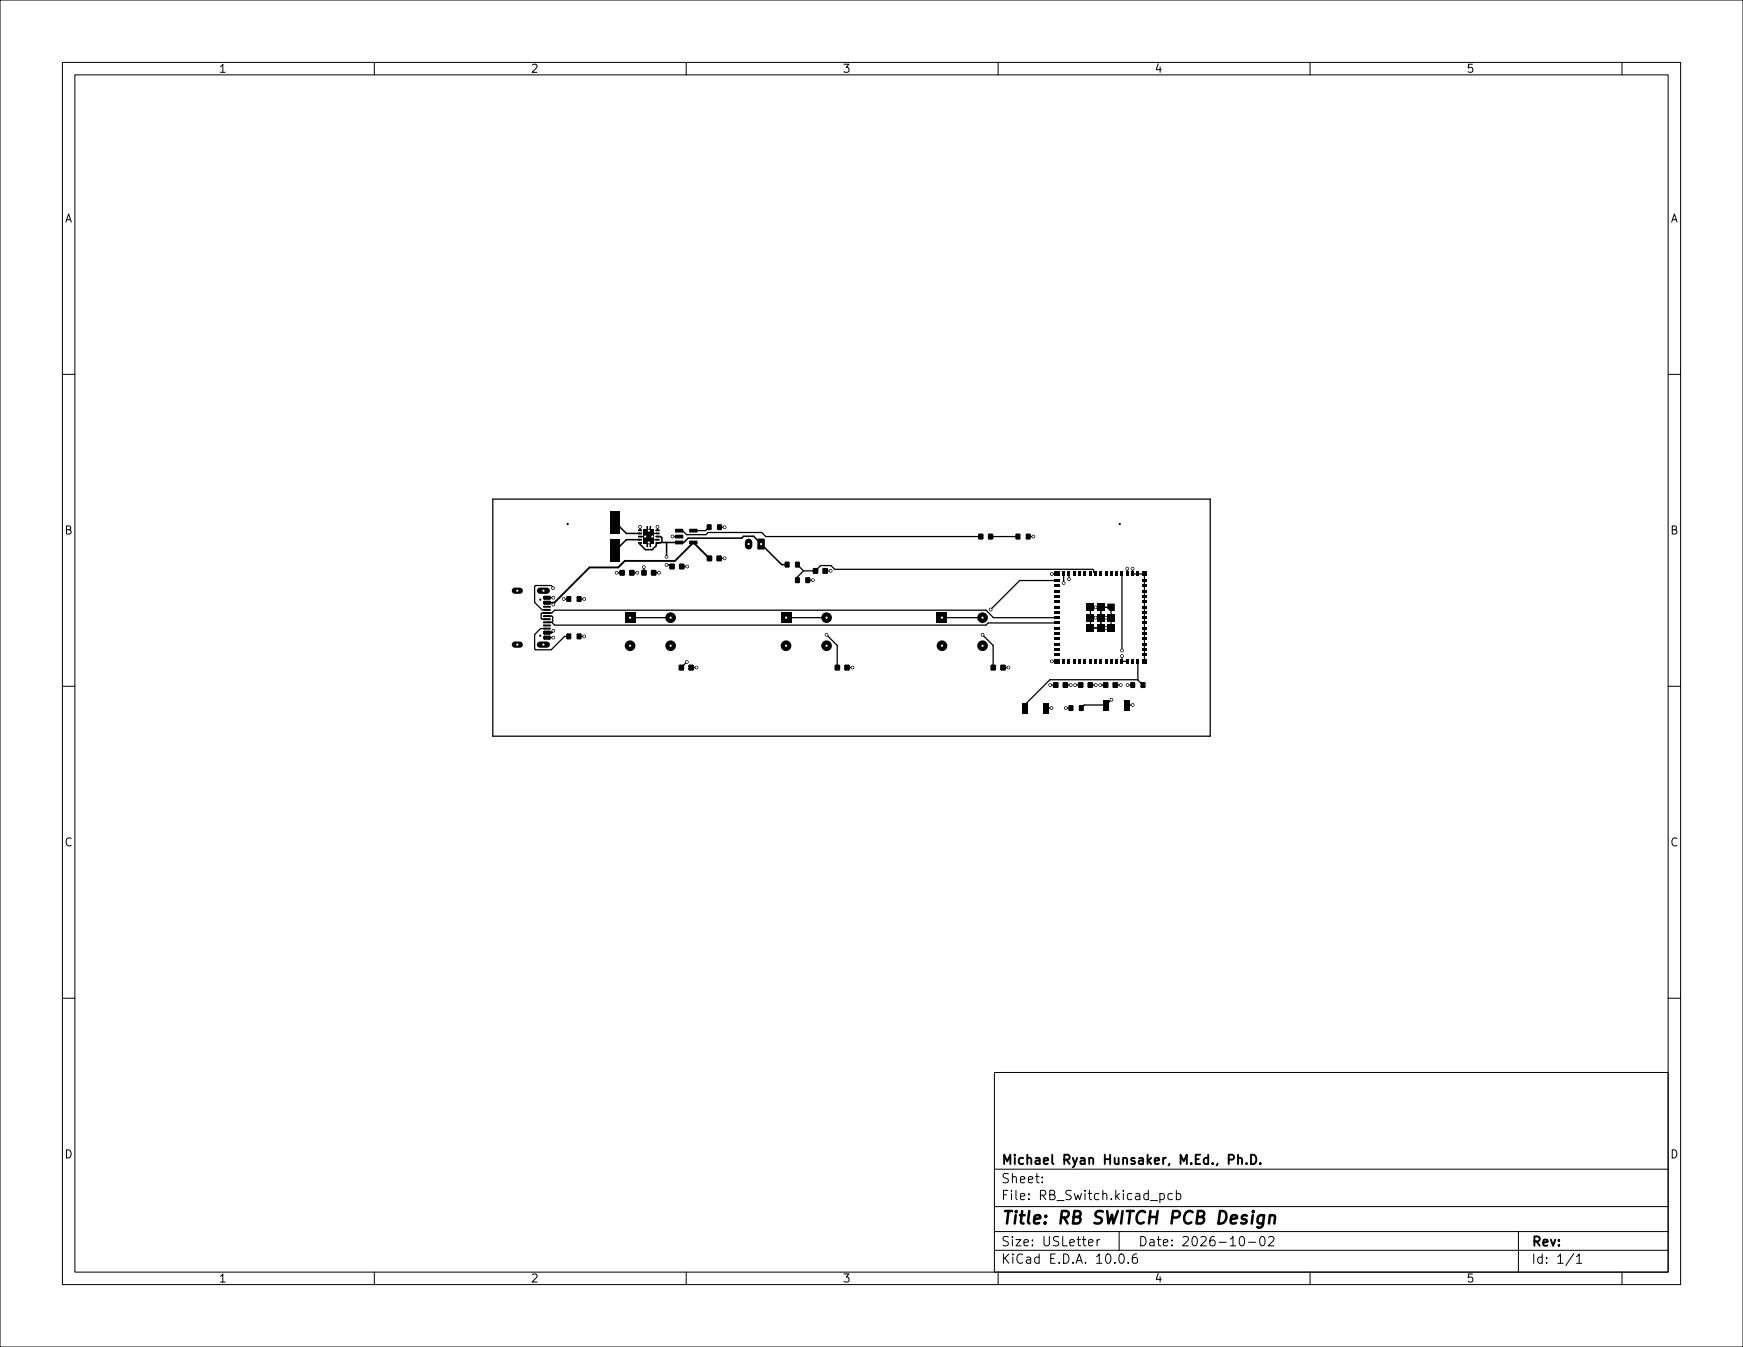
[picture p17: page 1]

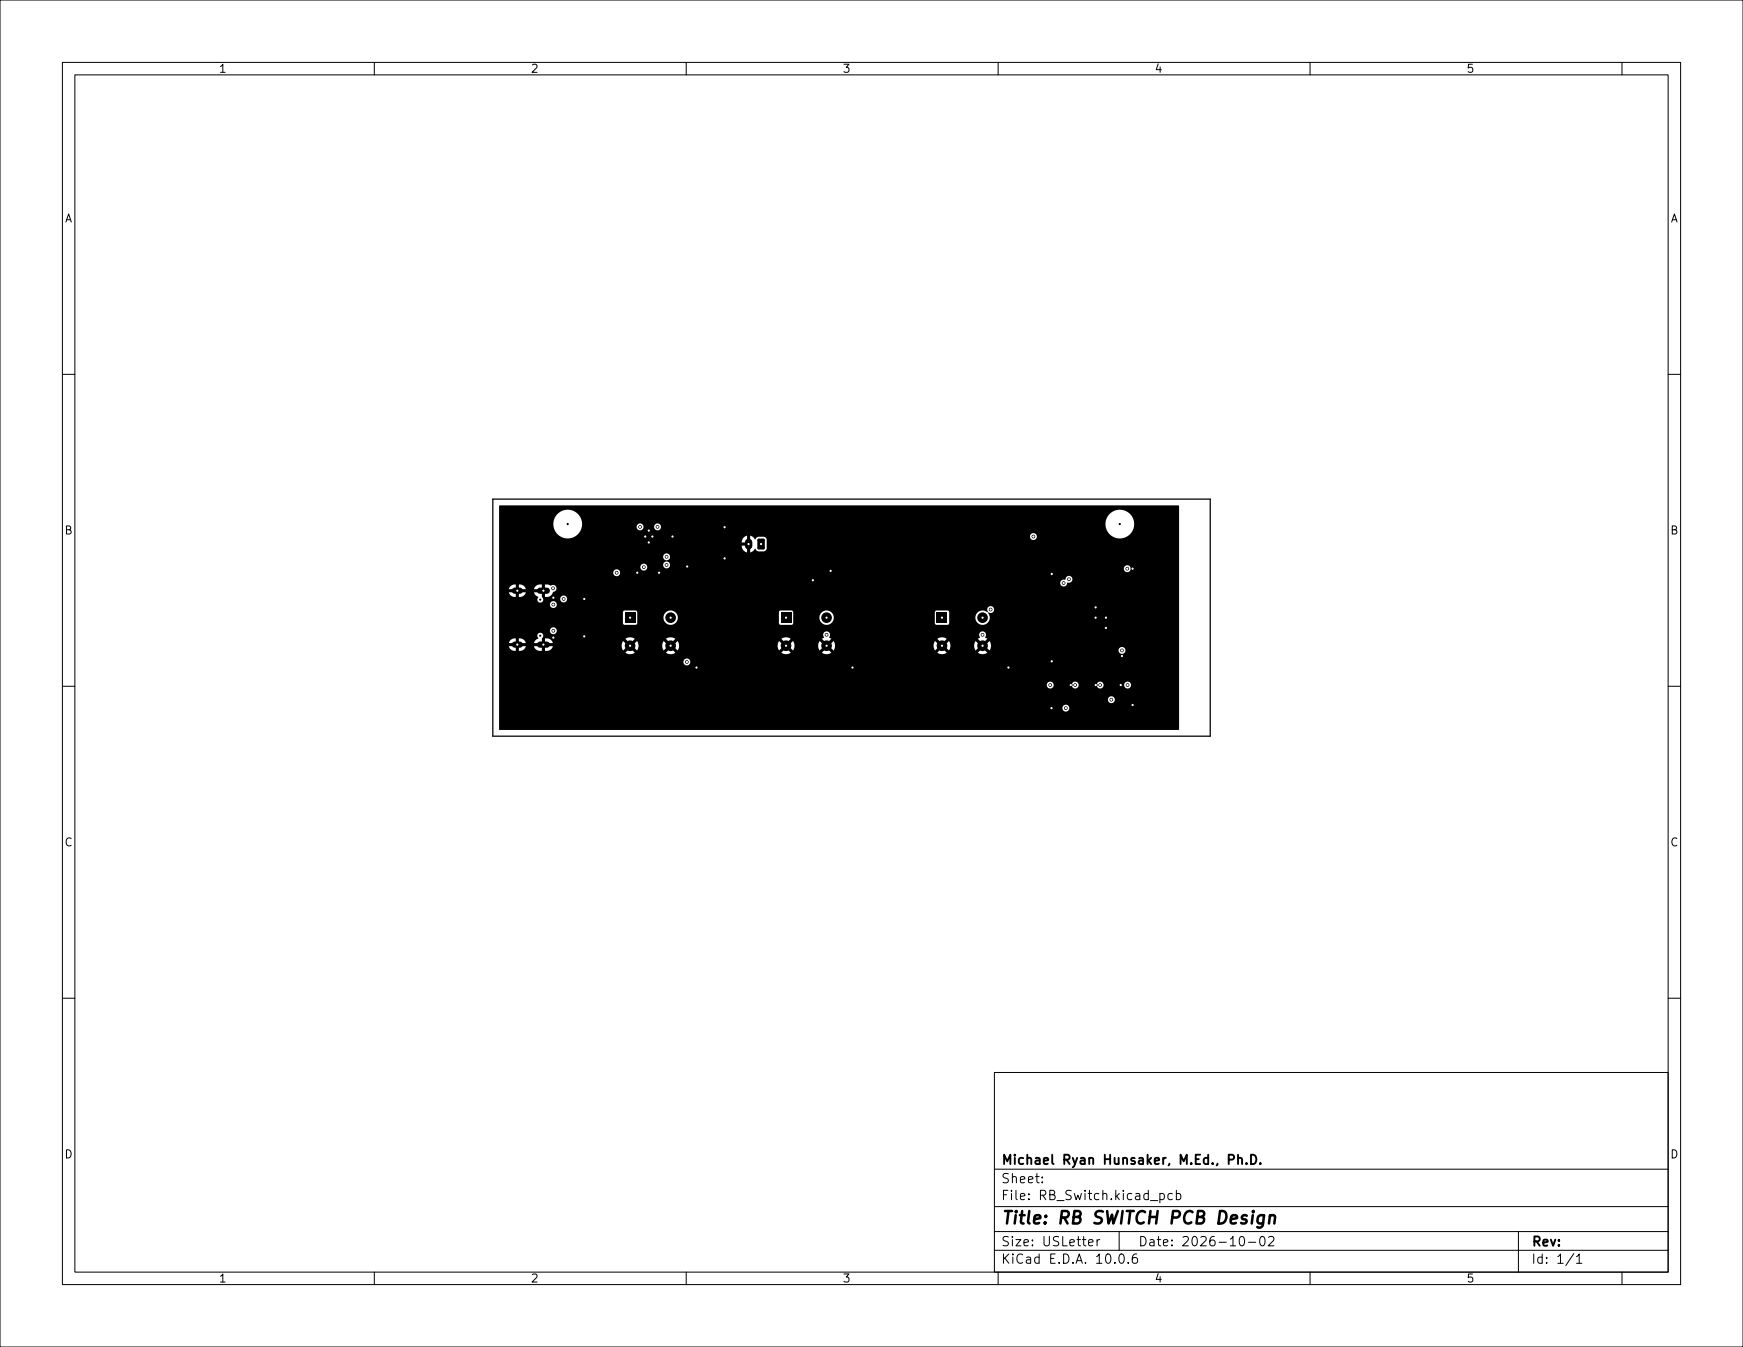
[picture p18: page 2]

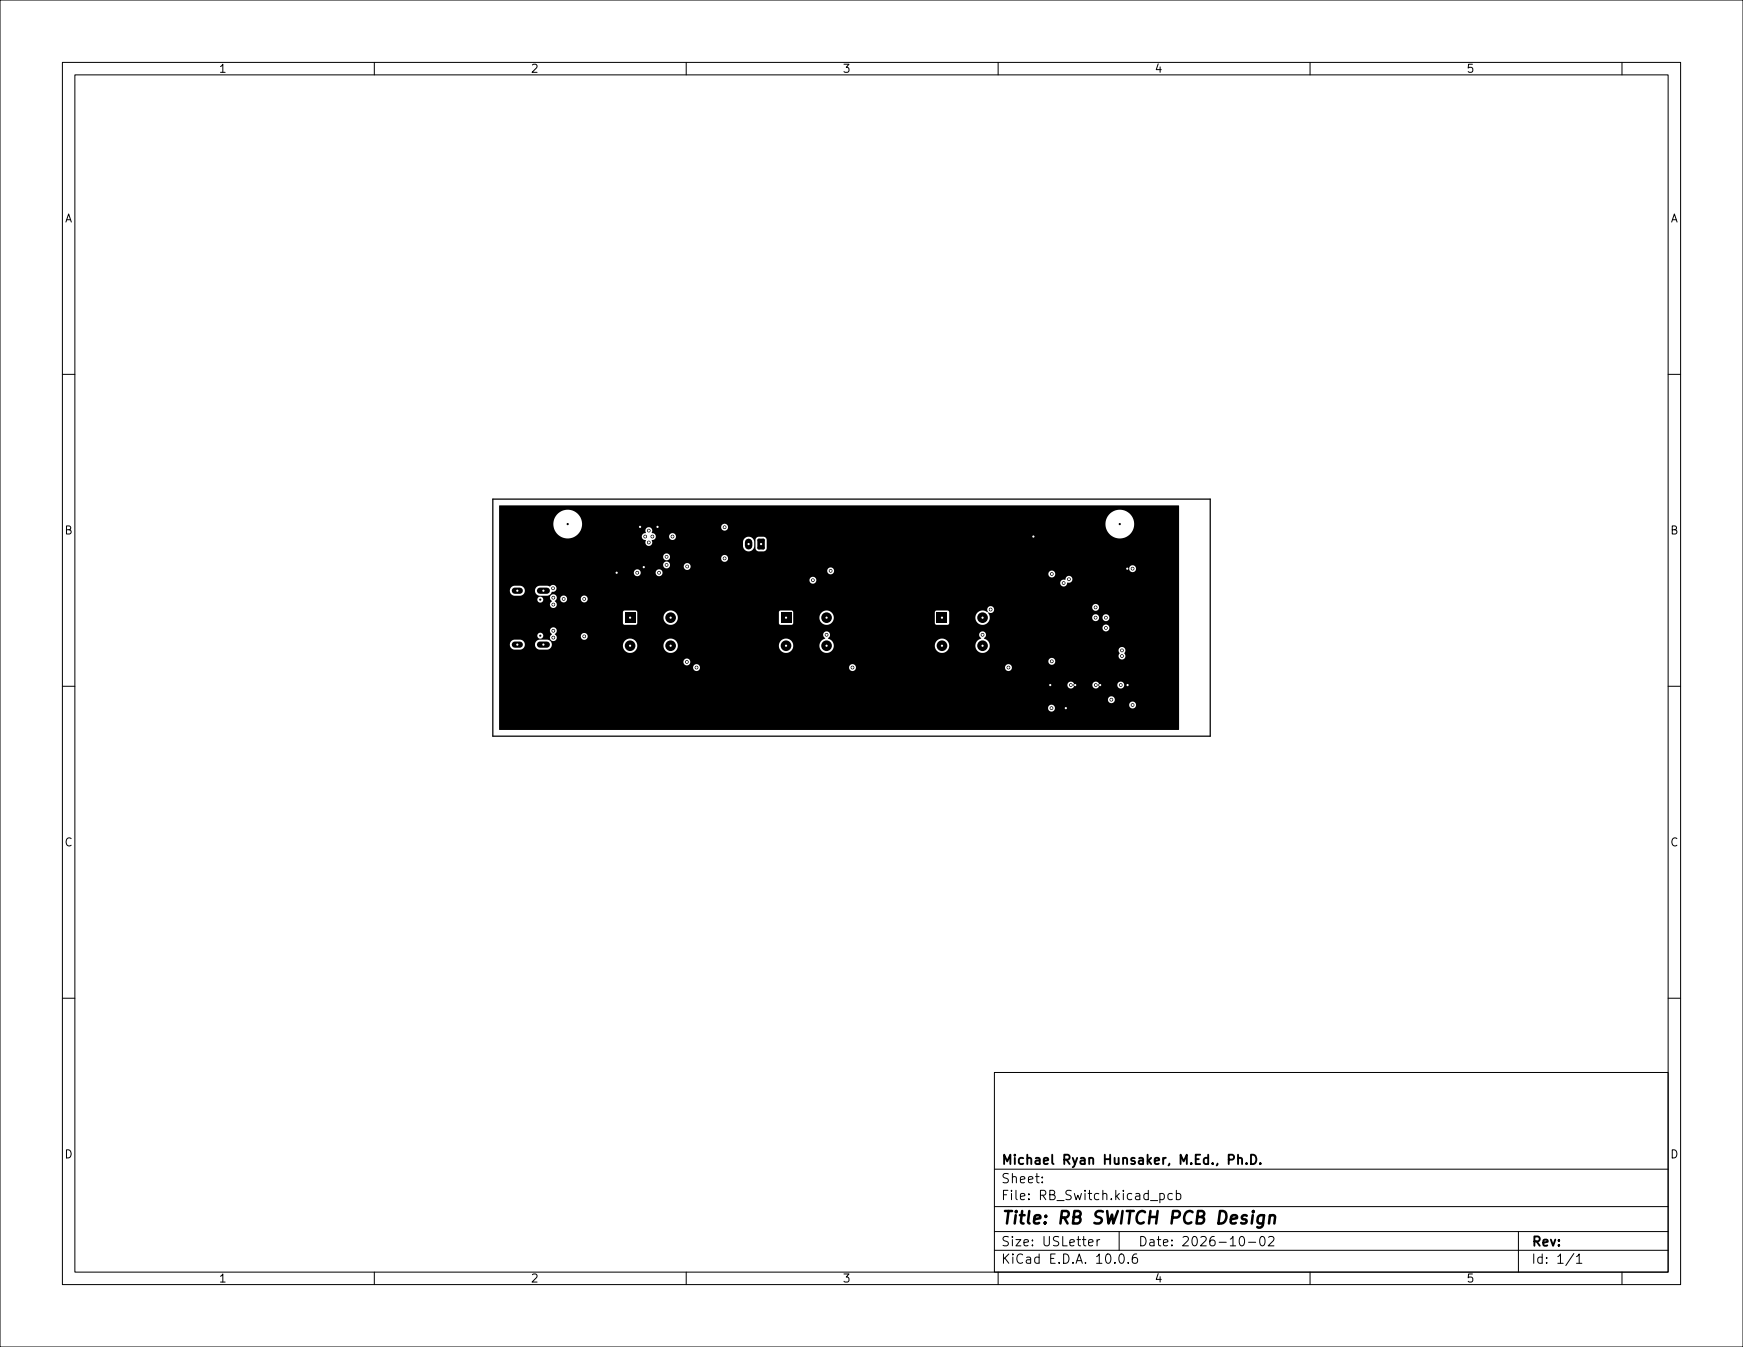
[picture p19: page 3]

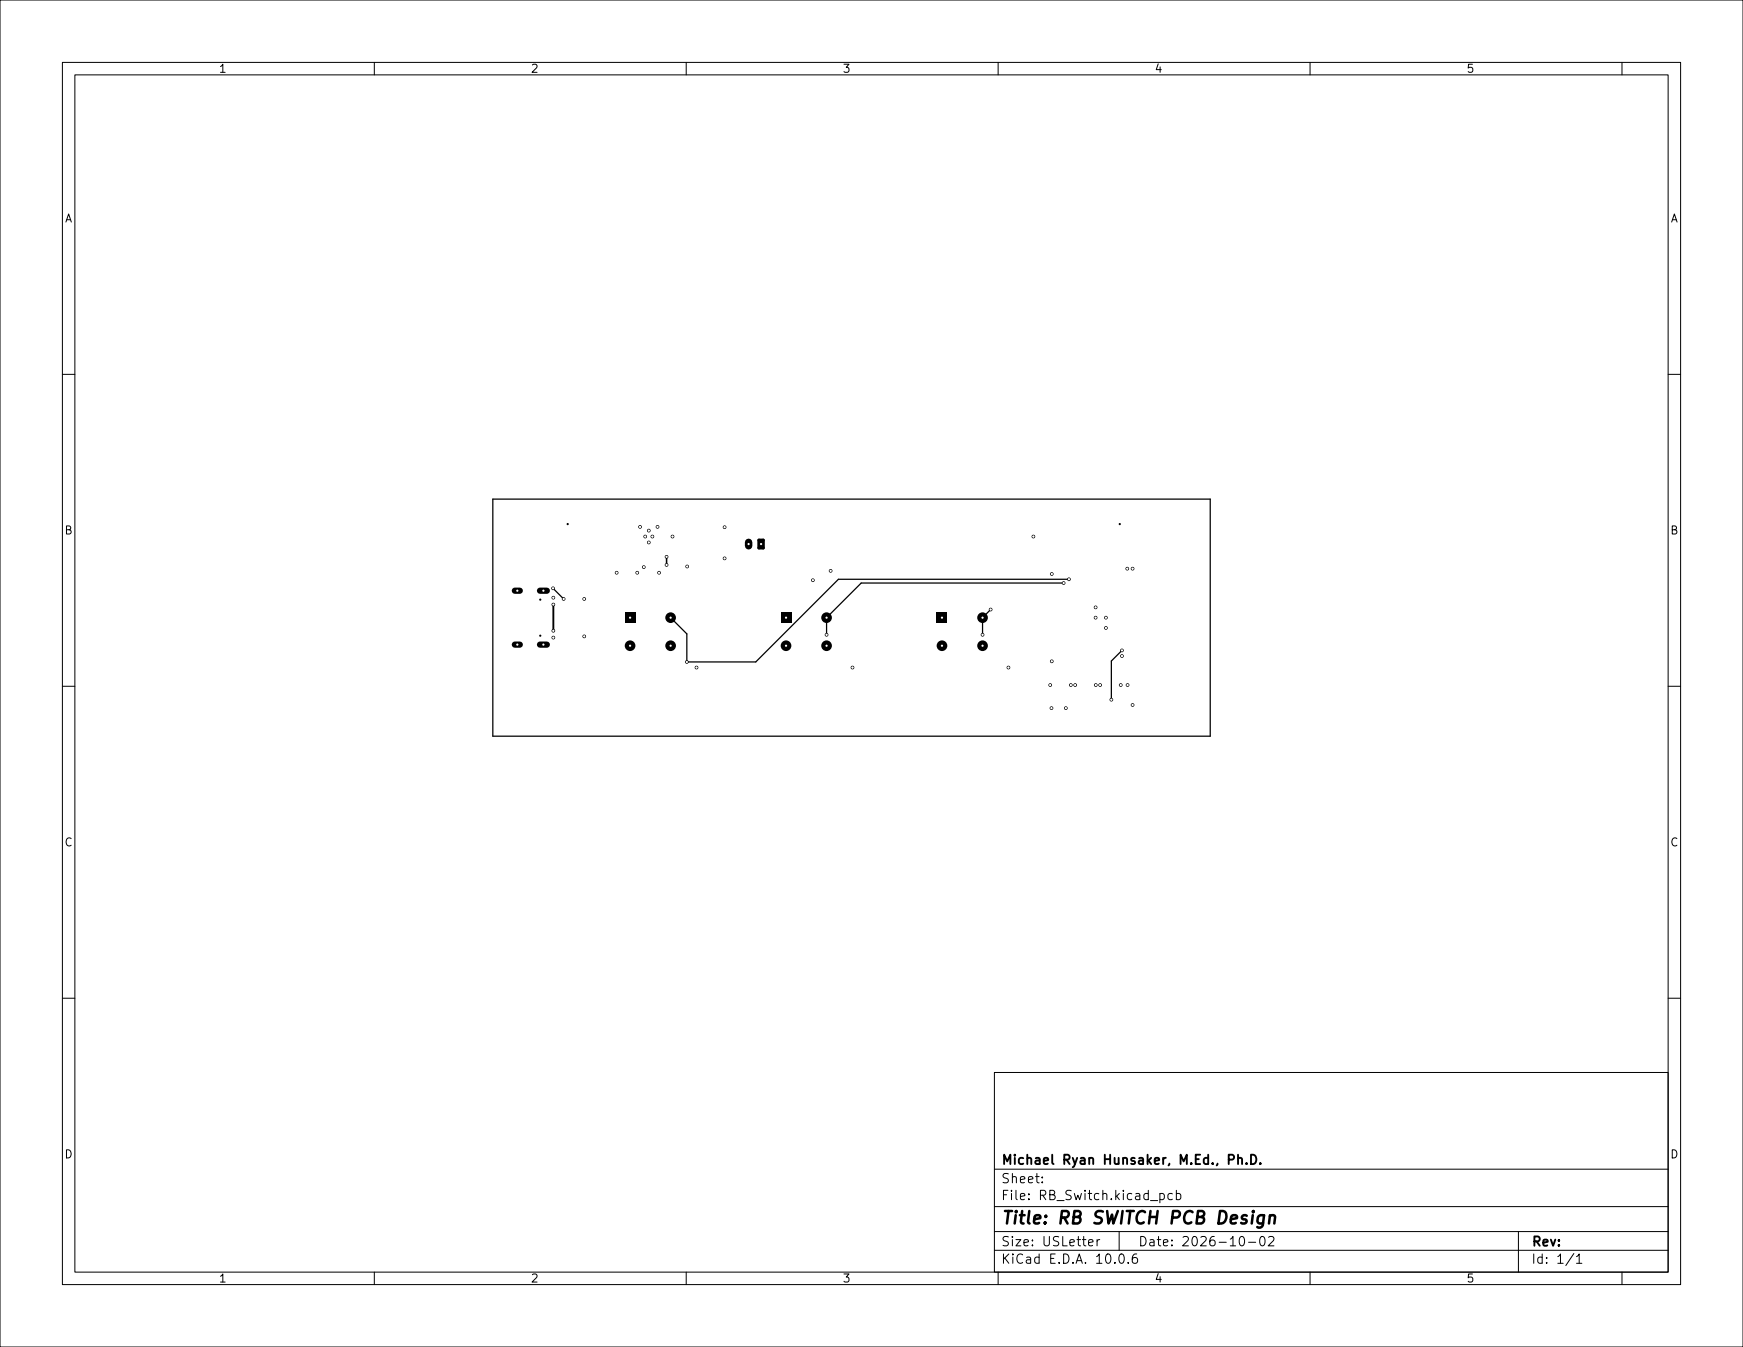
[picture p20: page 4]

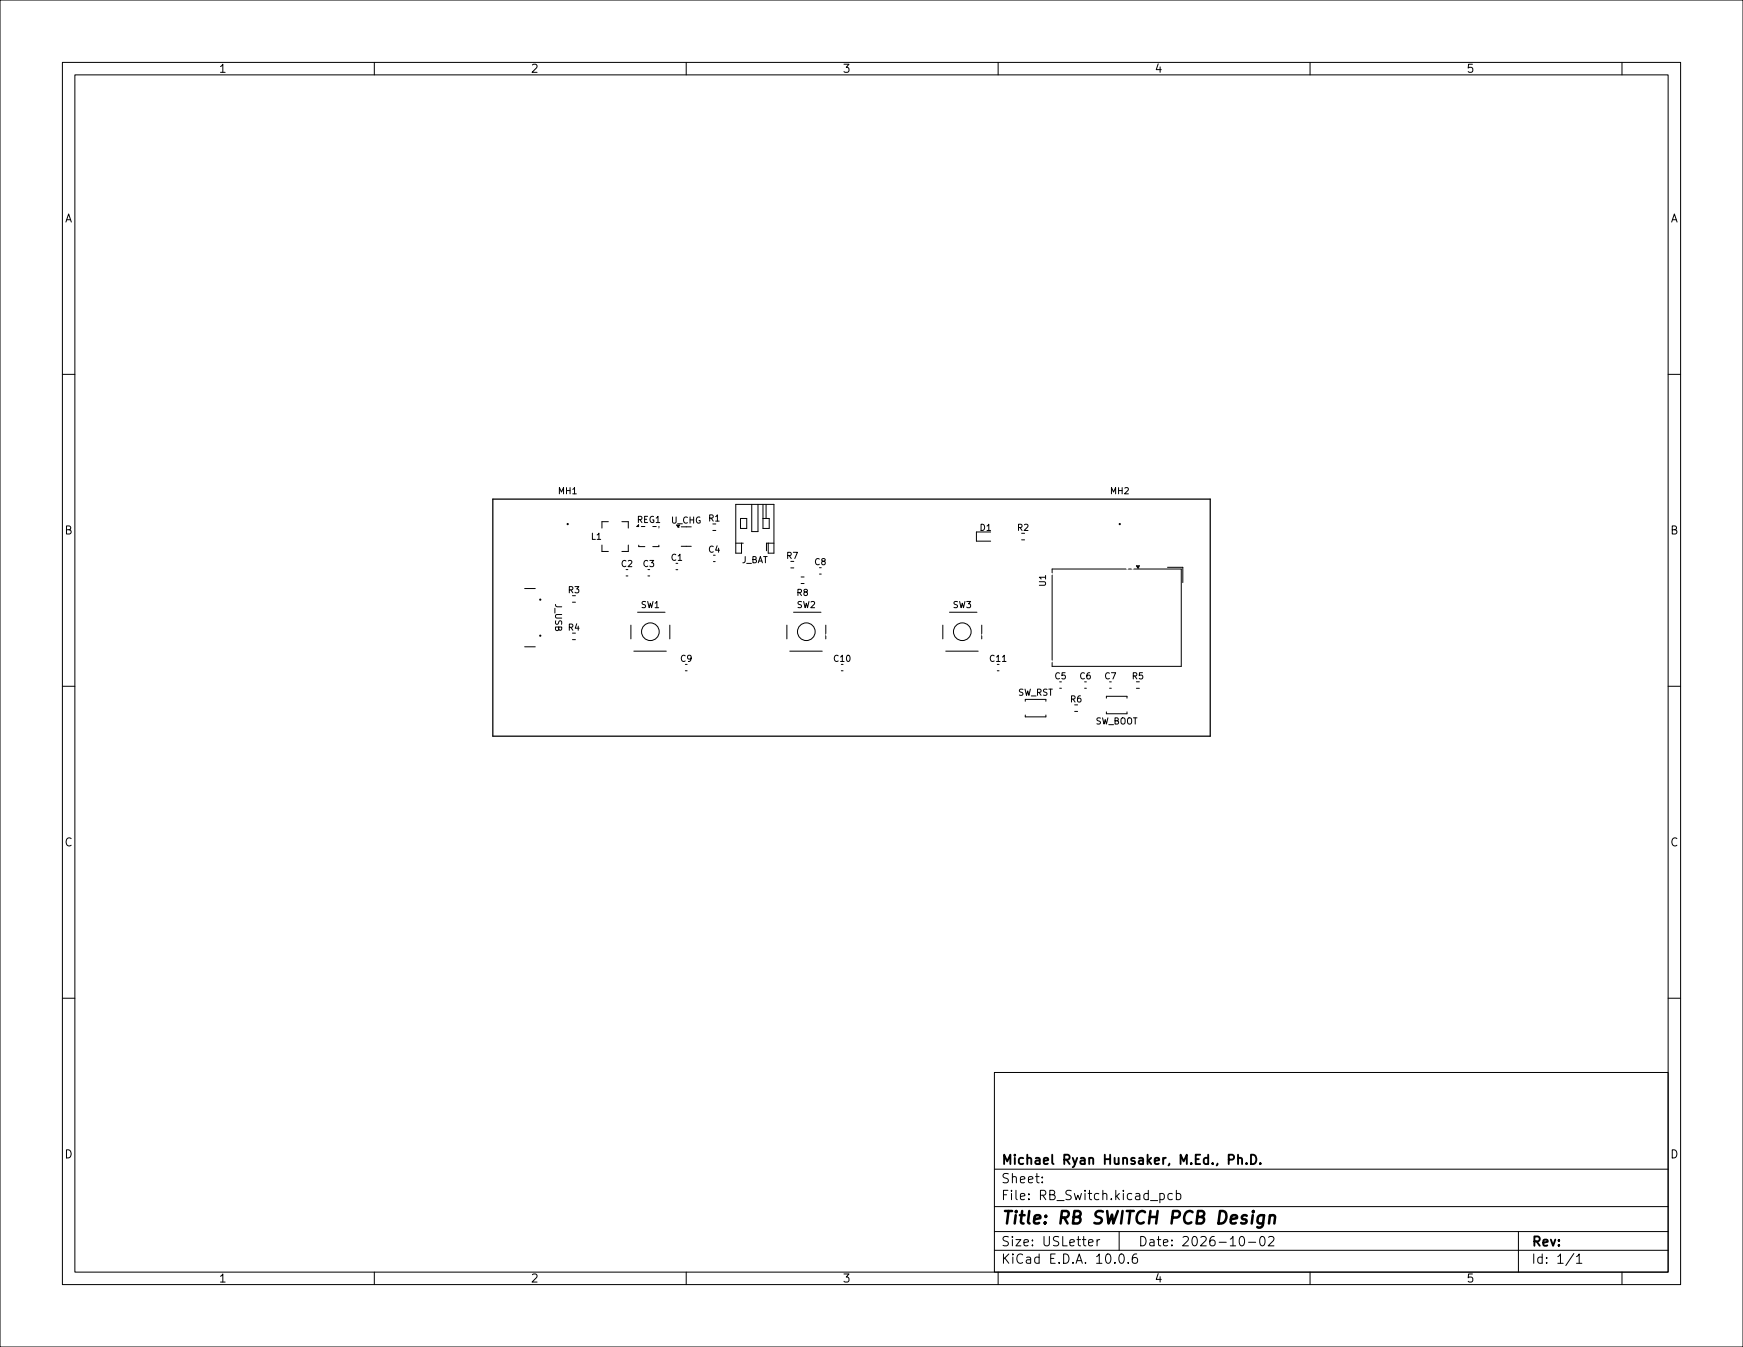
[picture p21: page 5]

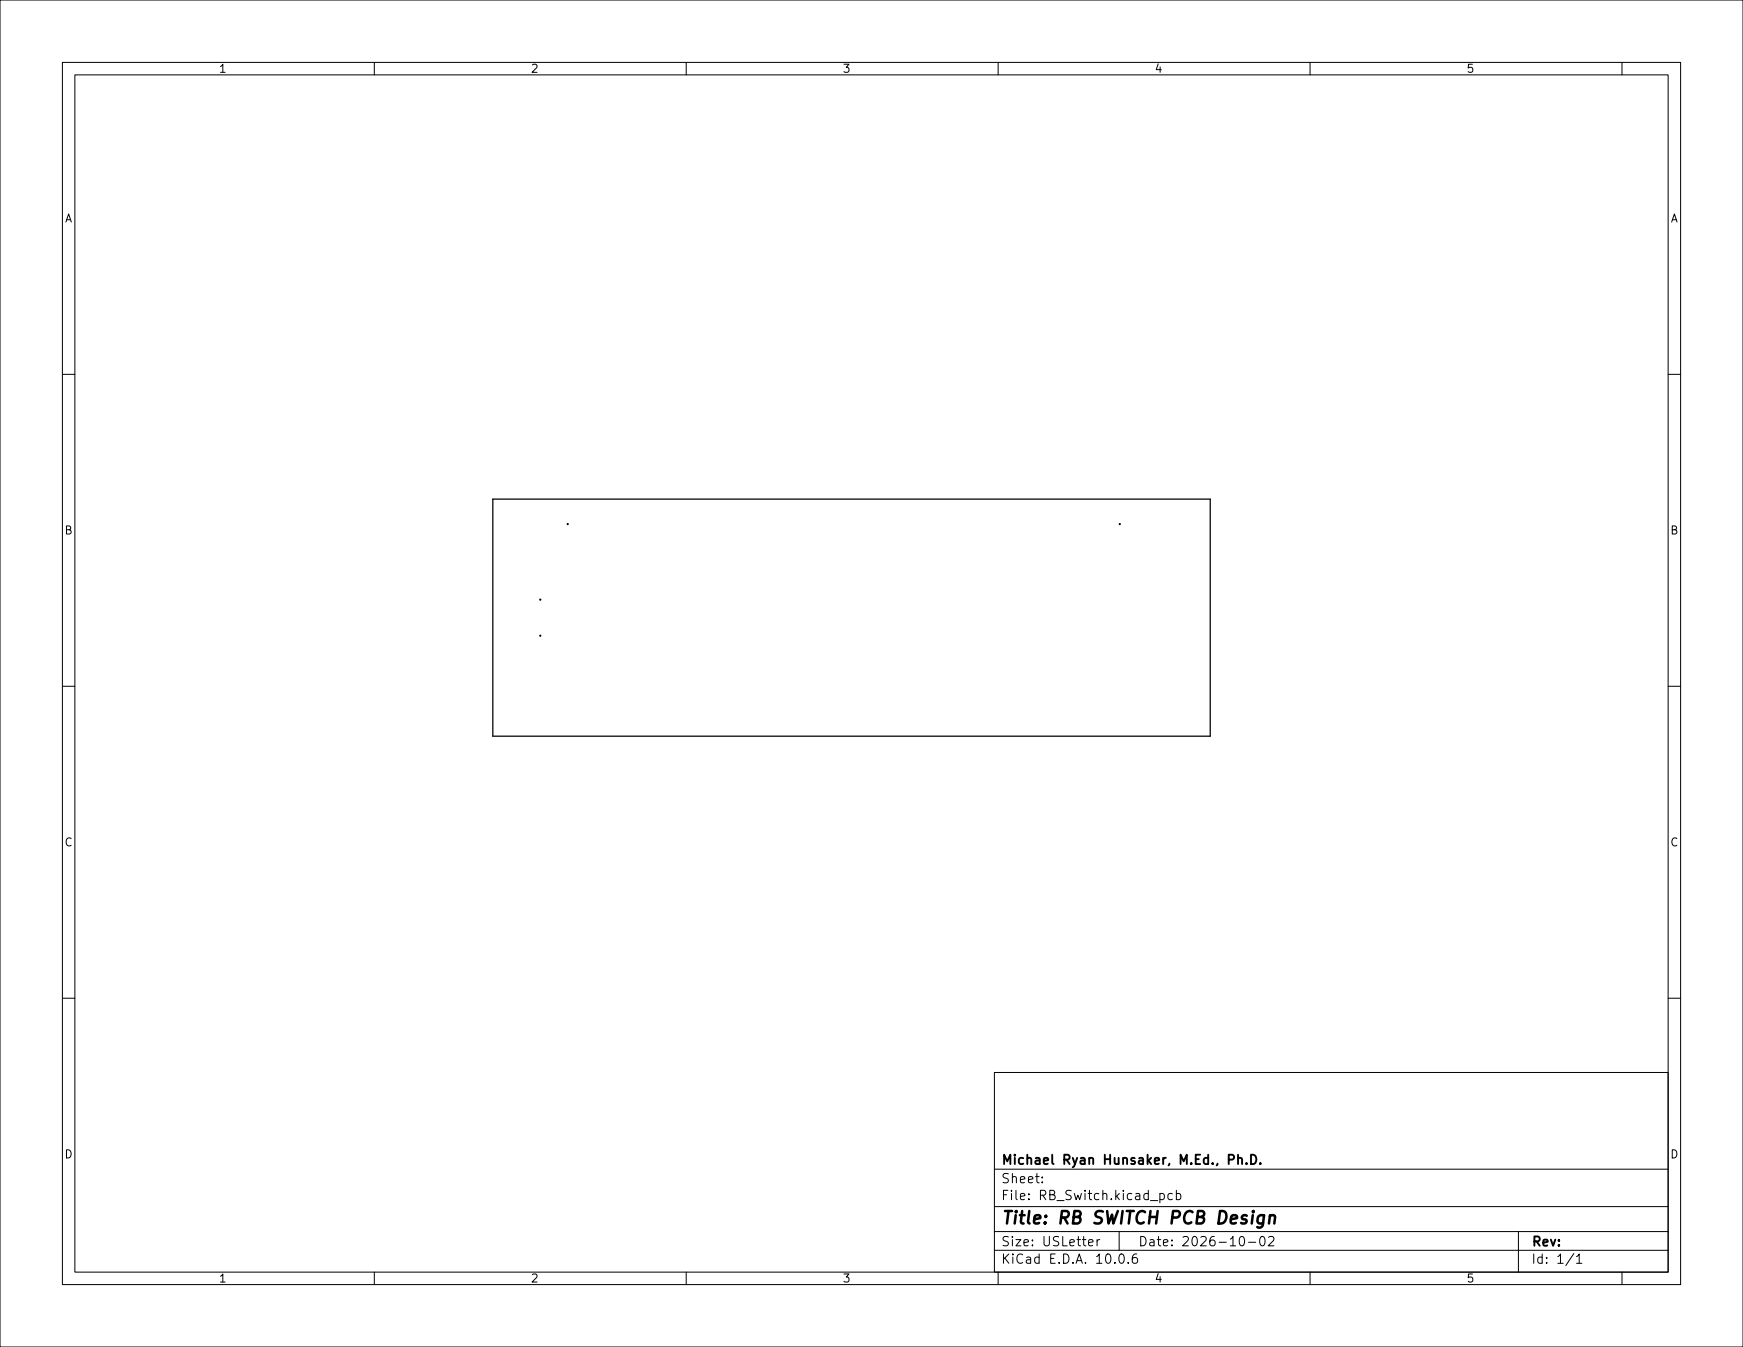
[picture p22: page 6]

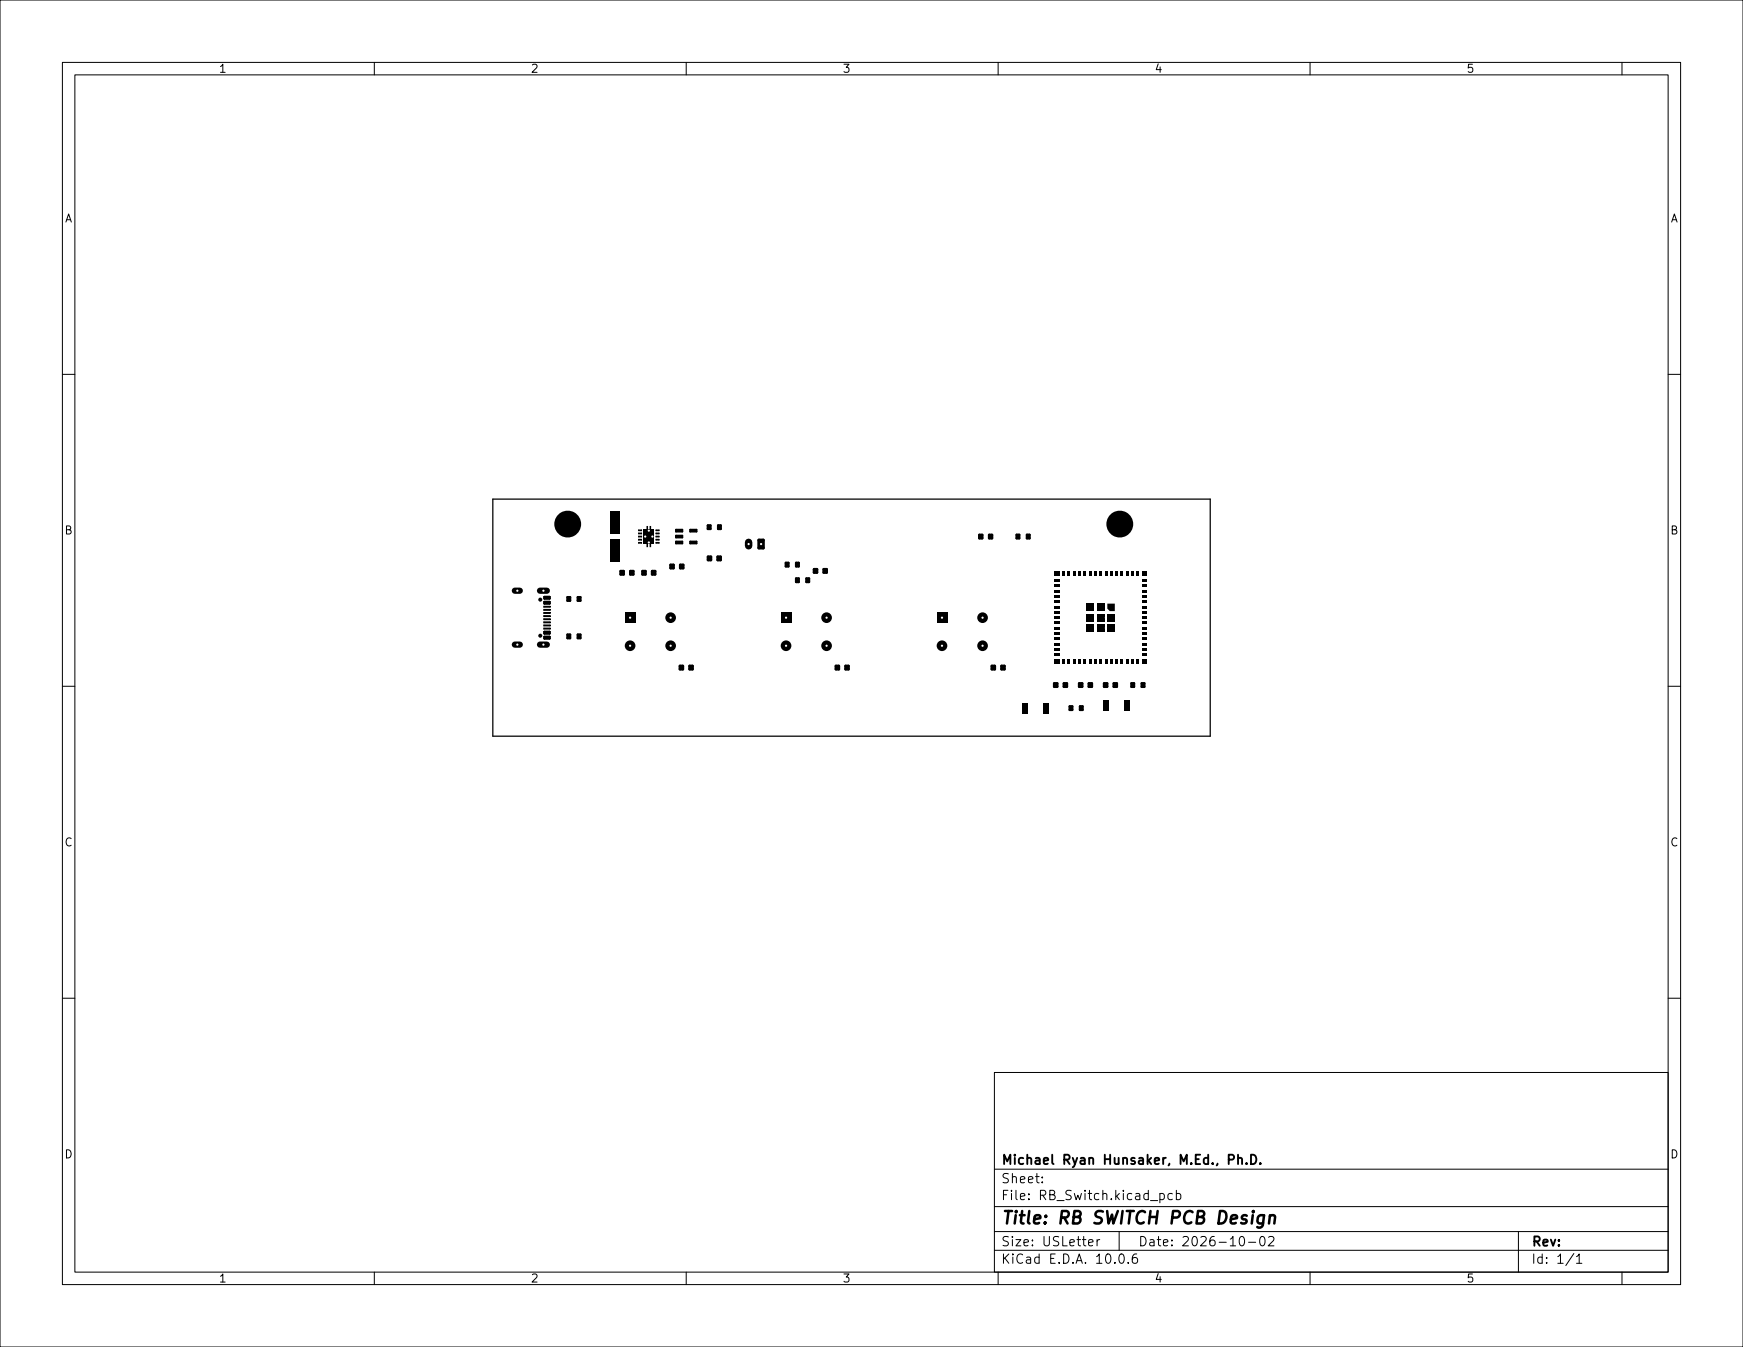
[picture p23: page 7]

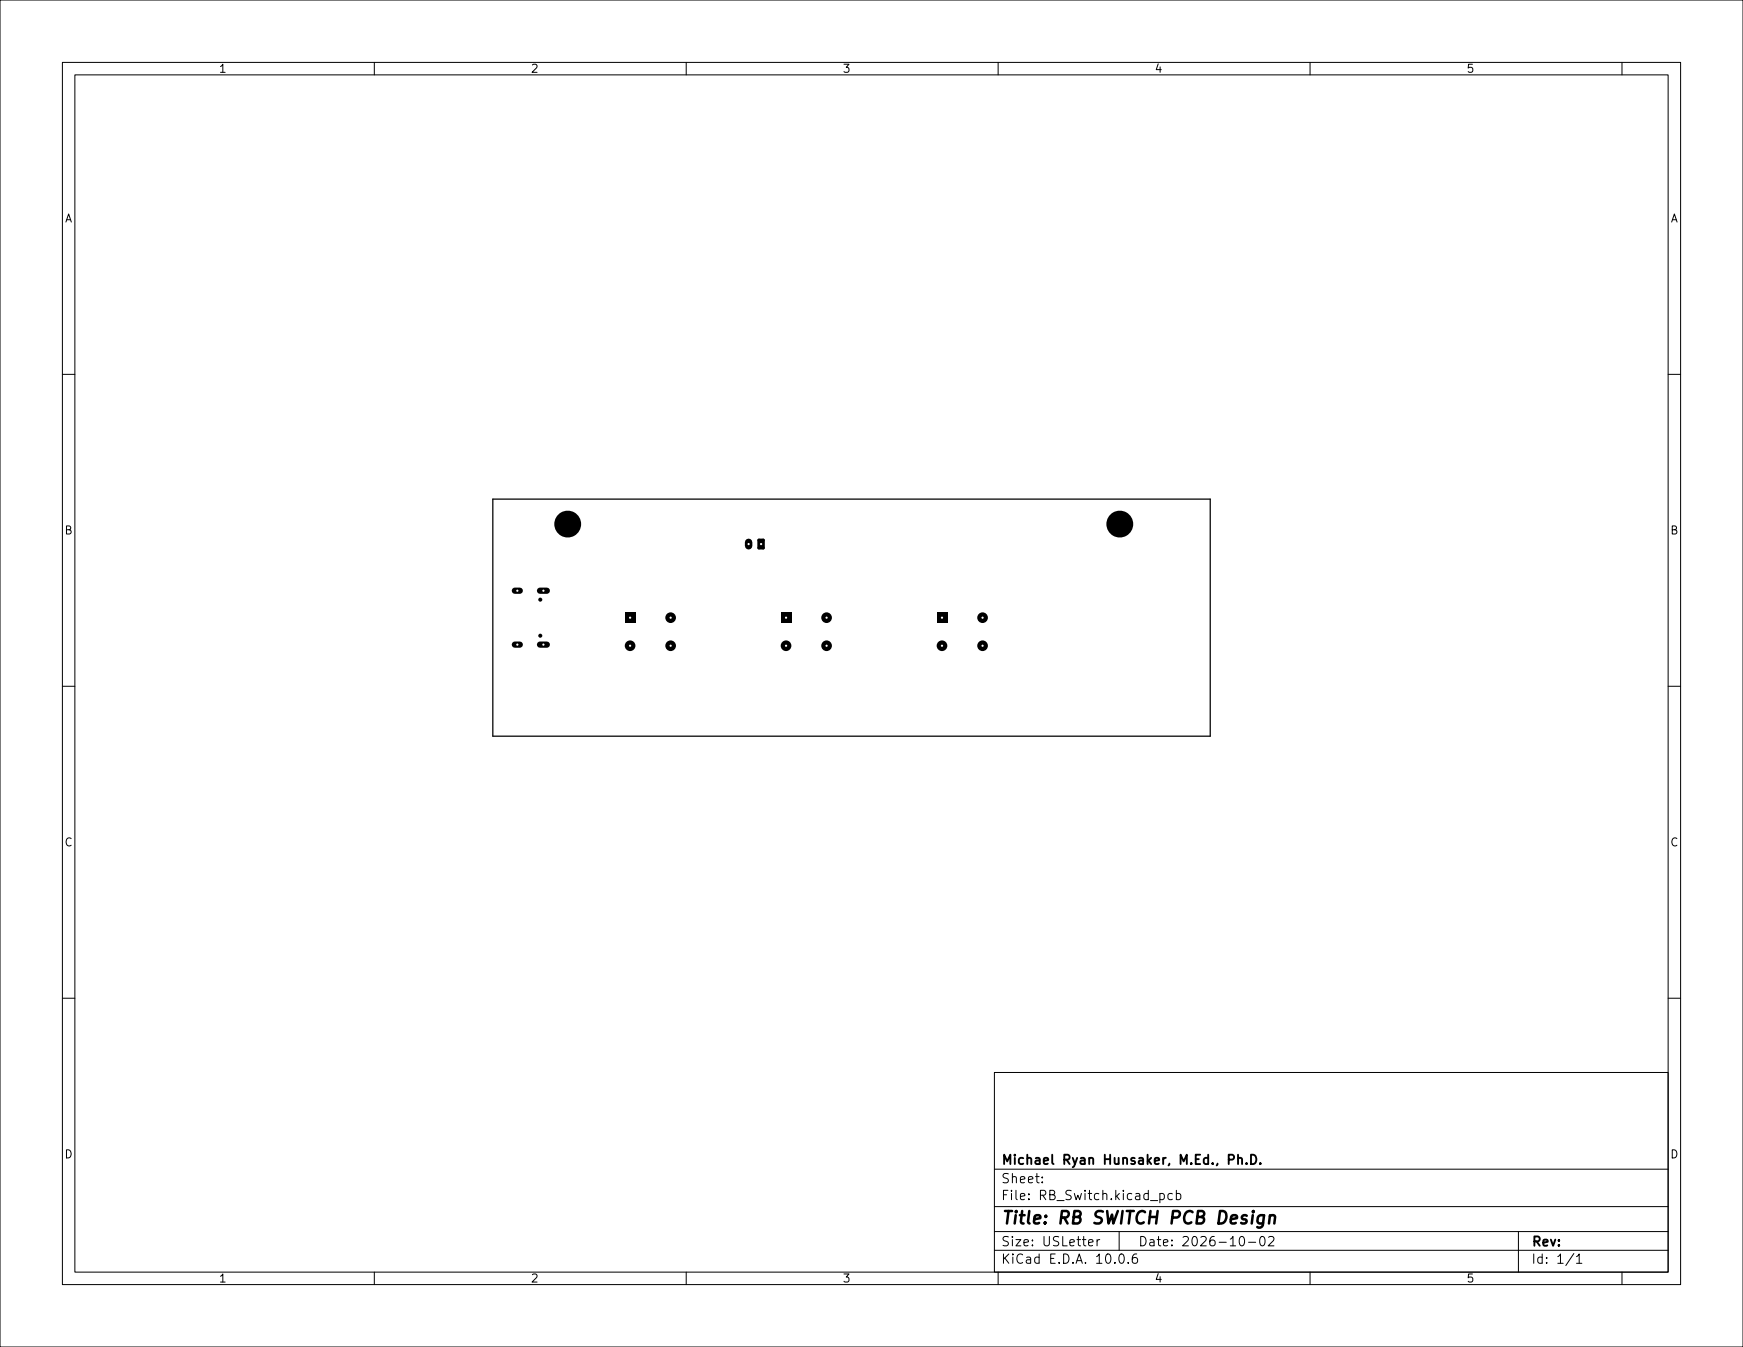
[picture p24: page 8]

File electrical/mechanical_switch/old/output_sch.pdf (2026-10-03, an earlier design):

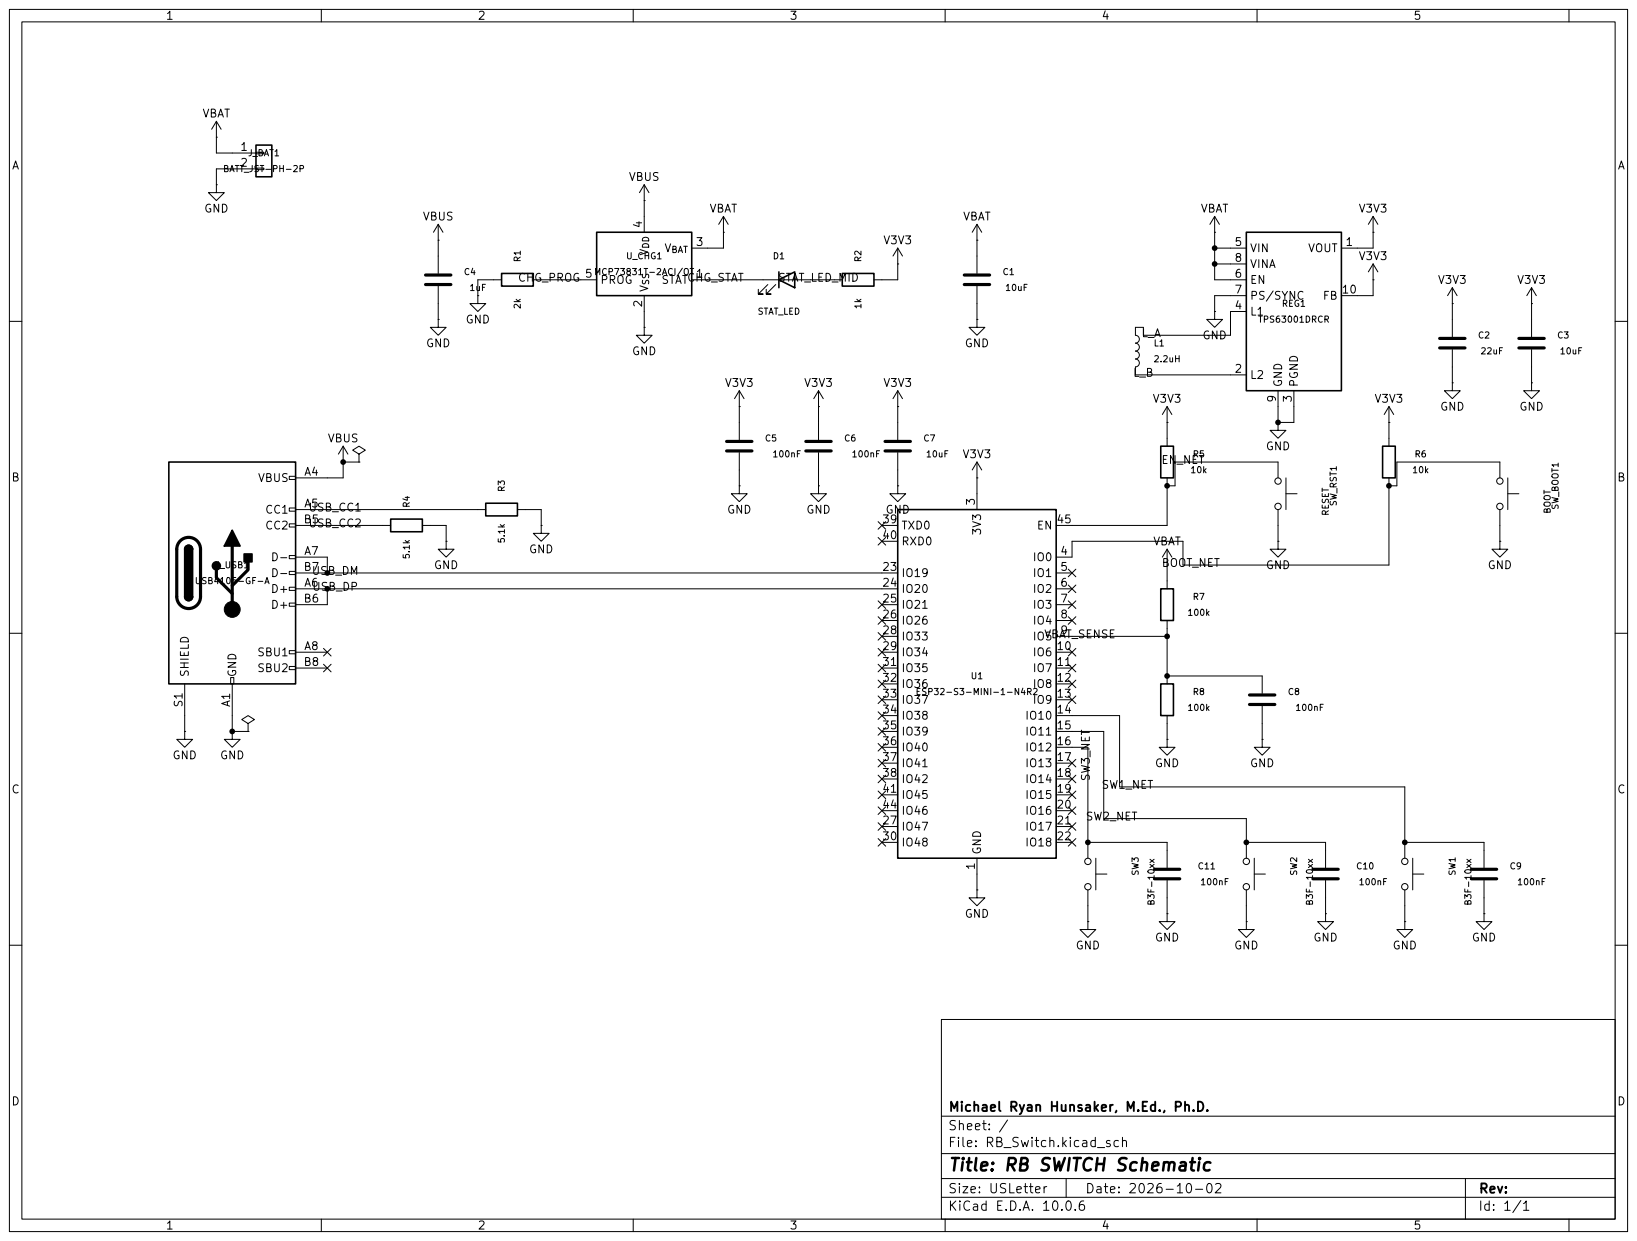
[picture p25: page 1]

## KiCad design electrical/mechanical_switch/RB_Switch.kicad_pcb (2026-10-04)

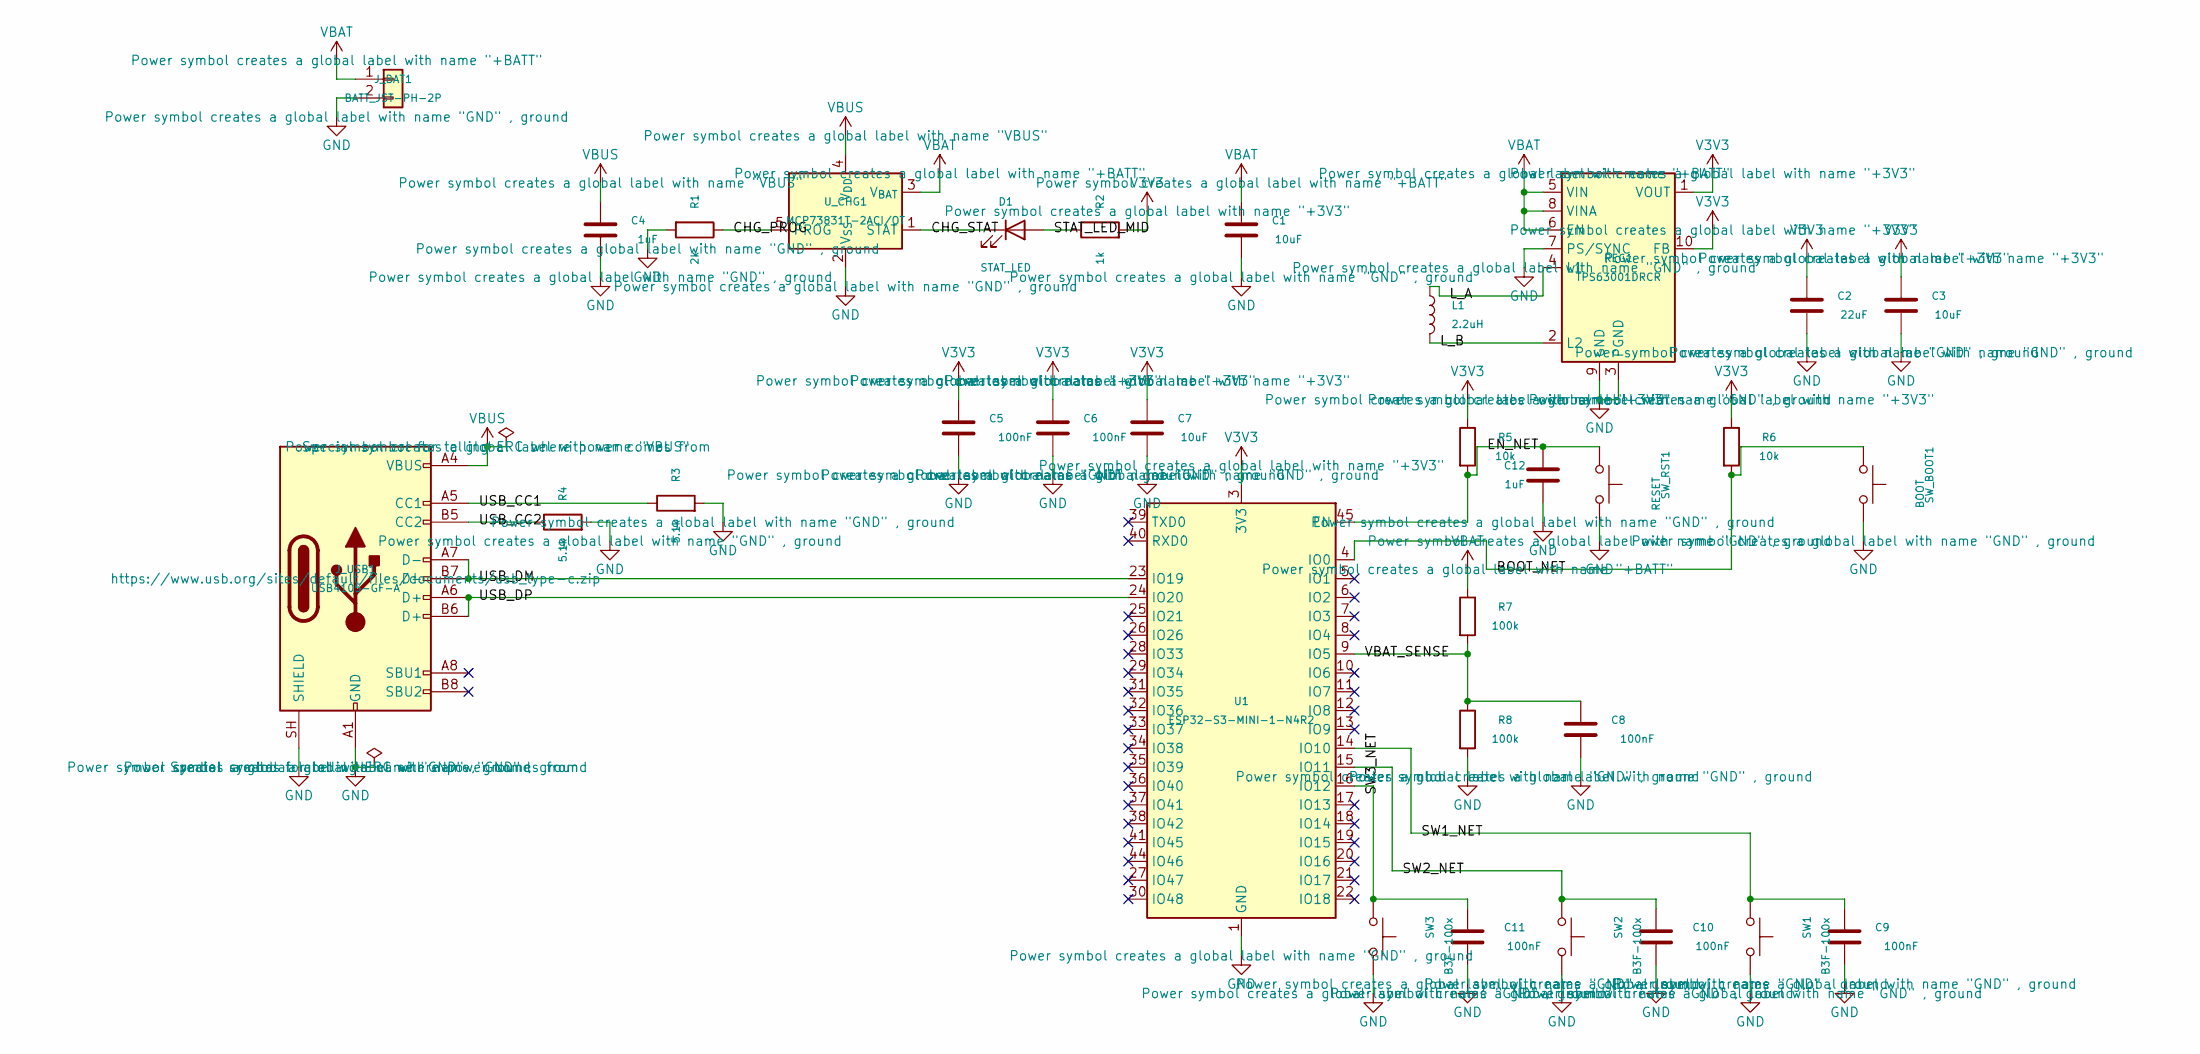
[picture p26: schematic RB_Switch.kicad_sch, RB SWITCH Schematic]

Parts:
C1, C3, C7: 10uF; C_0603_1608Metric
C2: 22uF; C_0603_1608Metric
C4, C12: 1uF; C_0603_1608Metric
C5, C6, C8, C9, C10, C11: 100nF; C_0603_1608Metric
D1: STAT_LED; LED_0603_1608Metric
J_BAT1: BATT_JST-PH-2P; JST_PH_S2B-PH-K_1x02_P2.00mm_Horizontal
J_USB1: USB4105-GF-A; USB_C_Receptacle_GCT_USB4105-xx-A_16P_TopMnt_Horizontal
L1: 2.2uH; L_Bourns-SRN4018
R1: 2k; R_0603_1608Metric
R2: 1k; R_0603_1608Metric
R3, R4: 5.1k; R_0603_1608Metric
R5, R6: 10k; R_0603_1608Metric
R7, R8: 100k; R_0603_1608Metric
REG1: TPS63001DRCR; Texas_DRC0010J
SW1, SW2, SW3: B3F-100x; SW_TH_Tactile_Omron_B3F-100x
SW_BOOT1: BOOT; SW_SPST_B3U-1000P
SW_RST1: RESET; SW_SPST_B3U-1000P
U1: ESP32-S3-MINI-1-N4R2; ESP32-S2-MINI-1
U_CHG1: MCP73831T-2ACI/OT; SOT-23-5

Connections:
/BOOT_NET: R6.2, SW_BOOT1.1, U1.4 (IO0)
/CHG_PROG: R1.1, U_CHG1.5 (PROG)
/CHG_STAT: D1.1 (K), U_CHG1.1 (STAT)
/EN_NET: C12.1, R5.2, SW_RST1.1, U1.45 (EN)
/L_A: L1.1, REG1.4 (L1)
/L_B: L1.2, REG1.2 (L2)
/STAT_LED_MID: D1.2 (A), R2.1
/SW1_NET: C9.1, SW1.1, U1.14 (IO10)
/SW2_NET: C10.1, SW2.1, U1.15 (IO11)
/SW3_NET: C11.1, SW3.1, U1.16 (IO12)
/USB_CC1: J_USB1.A5 (CC1), R3.1
/USB_CC2: J_USB1.B5 (CC2), R4.1
/USB_DM: J_USB1.A7 (D-), J_USB1.B7 (D-), U1.23 (IO19)
/USB_DP: J_USB1.A6 (D+), J_USB1.B6 (D+), U1.24 (IO20)
/VBAT_SENSE: C8.1, R7.2, R8.1, U1.9 (IO5)
GND: C1.2, C2.2, C3.2, C4.2, C5.2, C6.2, C7.2, C8.2, C9.2, C10.2, C11.2, C12.2, J_BAT1.2, J_USB1.A1 (GND), J_USB1.A12 (GND), J_USB1.B1 (GND), J_USB1.B12 (GND), J_USB1.SH (SHIELD), R1.2, R3.2, R4.2, R8.2, REG1.3 (PGND), REG1.7 (PS/SYNC), REG1.9 (GND), REG1.11 (PGND), SW1.2, SW2.2, SW3.2, SW_BOOT1.2, SW_RST1.2, U1.1 (GND), U1.2 (GND), U1.42 (GND), U1.43 (GND), U1.46 (GND), U1.47 (GND), U1.48 (GND), U1.49 (GND), U1.50 (GND), U1.51 (GND), U1.52 (GND), U1.53 (GND), U1.54 (GND), U1.55 (GND), U1.56 (GND), U1.57 (GND), U1.58 (GND), U1.59 (GND), U1.60 (GND), U1.61 (GND), U1.62 (GND), U1.63 (GND), U1.64 (GND), U1.65 (GND), U_CHG1.2 (V_{SS})
V3V3: C2.1, C3.1, C5.1, C6.1, C7.1, R2.2, R5.1, R6.1, REG1.1 (VOUT), REG1.10 (FB), U1.3 (3V3)
VBAT: C1.1, J_BAT1.1, R7.1, REG1.5 (VIN), REG1.6 (EN), REG1.8 (VINA), U_CHG1.3 (V_{BAT})
VBUS: C4.1, J_USB1.A4 (VBUS), J_USB1.A9 (VBUS), J_USB1.B4 (VBUS), J_USB1.B9 (VBUS), U_CHG1.4 (V_{DD})

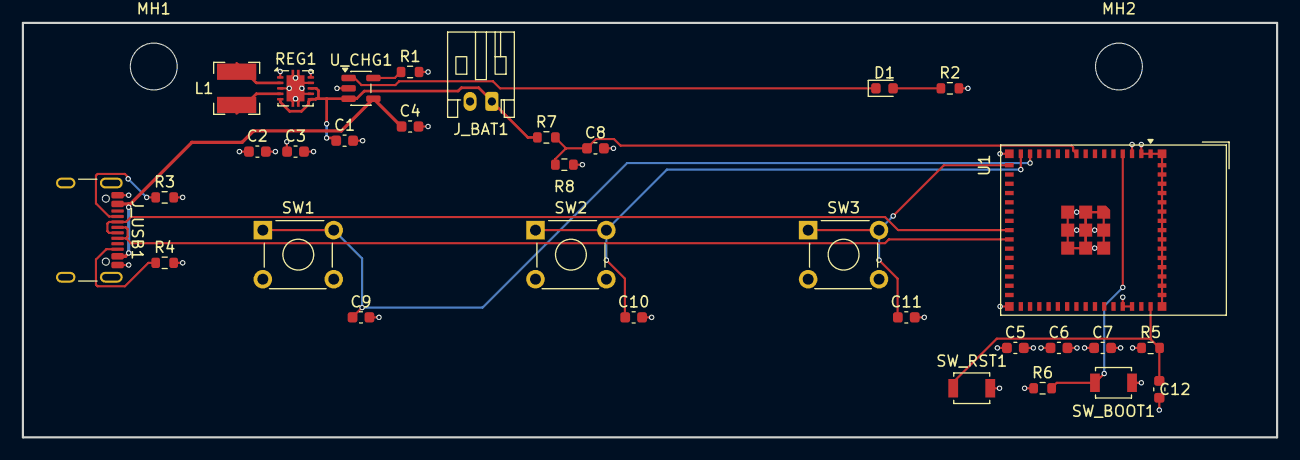
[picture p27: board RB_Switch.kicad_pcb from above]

Board: 4 copper layers, 115.0 x 38.0 mm, 34 parts (0 on the bottom side), 19 nets.

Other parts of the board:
MH1, MH2: MountingHole; MountingHole_4.3mm_M4

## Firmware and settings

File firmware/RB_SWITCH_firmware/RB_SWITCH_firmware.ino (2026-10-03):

/*
 * RB_SWITCH_firmware.ino
 *
 * RB Switch - production firmware for the three-button mechanical-switch PCB
 * (RevD/RevD2 hardware; pin map matches the current KiCad schematic and PCB).
 *
 * Hardware inputs:
 *   SW1 -> GPIO10 -> Left Arrow
 *   SW2 -> GPIO11 -> Enter
 *   SW3 -> GPIO12 -> Right Arrow
 *
 * The switches are wired from the GPIO to GND. Each input therefore uses
 * INPUT_PULLUP and is considered active when the GPIO reads LOW.
 *
 * The device presents itself as a standard BLE HID keyboard using NimBLE.
 * Each switch produces one press/release event on the activation edge.
 *
 * Deliberately NOT included:
 *   - TTP223 touch sensors
 *   - proximity / I2C sensors
 *   - NeoPixel / RGB LED control
 *   - mono-jack inputs
 *   - unused expansion inputs
 *
 * Board target:
 *   ESP32-S3 module used by the project (select "ESP32S3 Dev Module"
 *   in Arduino IDE unless your board package/project build process specifies
 *   an equivalent ESP32-S3 target).
 *
 * Modifying this file (remapping keys, changing debounce timing, renaming
 * the BLE device, etc.)? See docs/firmware-customization.md for a guided
 * walkthrough and a HID Usage ID reference table before editing the
 * constants below.
 */

#include <Arduino.h>
#include <NimBLEDevice.h>
#include <NimBLEHIDDevice.h>

// -----------------------------------------------------------------------------
// Hardware pin map: matches the KiCad schematic/PCB in
// electrical/mechanical_switch/ (see docs/hardware.md).
//
//   /SW1_NET -> U1 pin 14 (IO10) -> GPIO10
//   /SW2_NET -> U1 pin 15 (IO11) -> GPIO11
//   /SW3_NET -> U1 pin 16 (IO12) -> GPIO12
//
// Other U1 connections on the board (not driven by this firmware):
//   /BOOT_NET    -> U1 pin 4  (IO0)  BOOT button, 10 k pull-up to 3V3
//   /EN_NET      -> U1 pin 45 (EN)   RESET button, 10 k pull-up to 3V3
//   /USB_DM      -> U1 pin 23 (IO19) native USB D-
//   /USB_DP      -> U1 pin 24 (IO20) native USB D+
//   /VBAT_SENSE  -> U1 pin 9  (IO5)  VBAT / 2 divider (100 k + 100 k), 100 nF;
//                                    not read yet, battery level is fixed
//                                    at 100 below.
// The charge-status LED (D1) is driven by the MCP73831, not by a GPIO.
// -----------------------------------------------------------------------------

static constexpr uint8_t SW1_PIN = 10;
static constexpr uint8_t SW2_PIN = 11;
static constexpr uint8_t SW3_PIN = 12;

// USB HID Usage IDs:
//   0x4F = Keyboard Right Arrow
//   0x50 = Keyboard Left Arrow
//   0x28 = Keyboard Return (Enter)
static constexpr uint8_t LEFT_ARROW = 0x50;
static constexpr uint8_t ENTER_KEY = 0x28;
static constexpr uint8_t RIGHT_ARROW = 0x4F;

static constexpr uint32_t DEBOUNCE_MS = 35;

// -----------------------------------------------------------------------------
// BLE HID state
// -----------------------------------------------------------------------------

NimBLEHIDDevice* hid = nullptr;
NimBLECharacteristic* inputReport = nullptr;
bool connected = false;

class ServerCallbacks : public NimBLEServerCallbacks {
  void onConnect(NimBLEServer* server, NimBLEConnInfo& connInfo) override {
    (void)server;
    (void)connInfo;
    connected = true;
    Serial.println("BLE connected");
  }

  void onDisconnect(NimBLEServer* server, NimBLEConnInfo& connInfo, int reason) override {
    (void)server;
    (void)connInfo;
    (void)reason;
    connected = false;
    Serial.println("BLE disconnected; restarting advertising");
    NimBLEDevice::startAdvertising();
  }
};

// -----------------------------------------------------------------------------
// Debounce state
// -----------------------------------------------------------------------------

struct SwitchState {
  uint8_t pin;
  uint8_t key;
  bool rawState;
  bool stableState;
  uint32_t lastChangeMs;
};

SwitchState sw1{ SW1_PIN, LEFT_ARROW, HIGH, HIGH, 0 };
SwitchState sw2{ SW2_PIN, ENTER_KEY, HIGH, HIGH, 0 };
SwitchState sw3{ SW3_PIN, RIGHT_ARROW, HIGH, HIGH, 0 };

// -----------------------------------------------------------------------------
// BLE HID keyboard
// -----------------------------------------------------------------------------

void sendKey(uint8_t keycode) {
  if (!connected) {
    Serial.println("Key ignored: BLE not connected");
    return;
  }

  // Report ID 1 + modifier + reserved + six key slots.
  uint8_t pressReport[9] = {
    0x01,  // Report ID
    0x00,  // No modifier
    0x00,  // Reserved
    keycode,
    0x00, 0x00, 0x00, 0x00, 0x00
  };

  uint8_t releaseReport[9] = {
    0x01,  // Report ID
    0x00,  // No modifier
    0x00,  // Reserved
    0x00, 0x00, 0x00, 0x00, 0x00, 0x00
  };

  inputReport->setValue(pressReport, sizeof(pressReport));
  inputReport->notify();

  delay(20);

  inputReport->setValue(releaseReport, sizeof(releaseReport));
  inputReport->notify();
}

void setupBLE() {
  NimBLEDevice::init("RB Switch");
  NimBLEDevice::setMTU(247);
  NimBLEDevice::setPower(ESP_PWR_LVL_P9);
  NimBLEDevice::setSecurityAuth(true, false, false);

  NimBLEServer* server = NimBLEDevice::createServer();
  server->setCallbacks(new ServerCallbacks());

  hid = new NimBLEHIDDevice(server);
  hid->setManufacturer("RB Switch");
  hid->setPnp(0x01, 0xFFFF, 0x0001, 0x0100);

  inputReport = hid->getInputReport(1);

  // Standard boot-compatible keyboard report:
  //   8 modifier bits
  //   1 reserved byte
  //   6 keycode bytes
  static const uint8_t reportMap[] = {
    0x05, 0x01,  // Usage Page (Generic Desktop)
    0x09, 0x06,  // Usage (Keyboard)
    0xA1, 0x01,  // Collection (Application)
    0x85, 0x01,  //   Report ID (1)

    0x05, 0x07,  //   Usage Page (Keyboard/Keypad)
    0x19, 0xE0,  //   Usage Minimum (Left Control)
    0x29, 0xE7,  //   Usage Maximum (Right GUI)
    0x15, 0x00,  //   Logical Minimum (0)
    0x25, 0x01,  //   Logical Maximum (1)
    0x75, 0x01,  //   Report Size (1)
    0x95, 0x08,  //   Report Count (8)
    0x81, 0x02,  //   Input (Data, Variable, Absolute)

    0x75, 0x08,  //   Report Size (8)
    0x95, 0x01,  //   Report Count (1)
    0x81, 0x01,  //   Input (Constant)

    0x75, 0x08,  //   Report Size (8)
    0x95, 0x06,  //   Report Count (6)
    0x15, 0x00,  //   Logical Minimum (0)
    0x25, 0x73,  //   Logical Maximum (115)
    0x05, 0x07,  //   Usage Page (Keyboard/Keypad)
    0x19, 0x00,  //   Usage Minimum (0)
    0x29, 0x73,  //   Usage Maximum (115)
    0x81, 0x00,  //   Input (Data, Array)

    0xC0  // End Collection
  };

  hid->setReportMap((uint8_t*)reportMap, sizeof(reportMap));
  hid->setBatteryLevel(100);

  NimBLEAdvertising* advertising = NimBLEDevice::getAdvertising();
  NimBLEAdvertisementData advertisementData;
  advertisementData.setFlags(0x06);
  advertisementData.setName("RB Switch");
  advertisementData.addServiceUUID(NimBLEUUID("1812"));  // HID service
  advertising->setAdvertisementData(advertisementData);
  advertising->setMinInterval(32);
  advertising->setMaxInterval(48);
  advertising->start();

  Serial.println("BLE advertising as \"RB Switch\"");
}

// -----------------------------------------------------------------------------
// Switch handling
// -----------------------------------------------------------------------------

void updateSwitch(SwitchState& sw) {
  // Active LOW: HIGH = released, LOW = pressed.
  const bool raw = digitalRead(sw.pin);
  const uint32_t now = millis();

  if (raw != sw.rawState) {
    sw.rawState = raw;
    sw.lastChangeMs = now;
  }

  if ((now - sw.lastChangeMs) >= DEBOUNCE_MS && sw.stableState != sw.rawState) {

    sw.stableState = sw.rawState;

    // Fire only on the transition to pressed.
    if (sw.stableState == LOW) {
      Serial.printf("SW GPIO%u -> HID 0x%02X\n", sw.pin, sw.key);
      sendKey(sw.key);
    }
  }
}

// -----------------------------------------------------------------------------
// Arduino setup / loop
// -----------------------------------------------------------------------------

void setup() {
  Serial.begin(115200);
  delay(250);

  pinMode(SW1_PIN, INPUT_PULLUP);
  pinMode(SW2_PIN, INPUT_PULLUP);
  pinMode(SW3_PIN, INPUT_PULLUP);

  // Initialize debounce states from the actual switch state so a held
  // switch during boot does not generate a phantom transition.
  const uint32_t now = millis();
  sw1.rawState = sw1.stableState = digitalRead(sw1.pin);
  sw2.rawState = sw2.stableState = digitalRead(sw2.pin);
  sw3.rawState = sw3.stableState = digitalRead(sw3.pin);
  sw1.lastChangeMs = now;
  sw2.lastChangeMs = now;
  sw3.lastChangeMs = now;

  Serial.println();
  Serial.println("RB Switch firmware");
  Serial.println("SW1 GPIO10 -> Left Arrow");
  Serial.println("SW2 GPIO11 -> Enter");
  Serial.println("SW3 GPIO12 -> Right Arrow");

  setupBLE();
}

void loop() {
  updateSwitch(sw1);
  updateSwitch(sw2);
  updateSwitch(sw3);
  delay(1);
}

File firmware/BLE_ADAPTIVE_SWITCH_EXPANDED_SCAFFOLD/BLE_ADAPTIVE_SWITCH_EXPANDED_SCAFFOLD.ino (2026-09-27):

// =====================================================================
// BLE ADAPTIVE SWITCH NODE — EXPANDED SCAFFOLD  (v3, I2C removed)
// Board : ESP32-S3 SuperMini  (ESP32S3FH4R2 — in-package flash+PSRAM)
// Target: NimBLE HID keyboard over BLE → iPadOS Switch Control
//
// Pin layout — verified against board's actual header positions:
//
//   LEFT HEADER  (top→bottom)
//     GPIO  1, 2, 4, 5, 6, 7 → TTP223 capacitive touch (6 sensors)
//       ⚠  GPIO 3 is a strapping pin. TTP223 rests LOW when untouched,
//          which is the safe boot-time state. Do NOT touch the pad
//          connected to GPIO 3 while powering on or pressing RESET.
//
//   RIGHT HEADER (top→bottom from 3V3 pin)
//     GPIO 8, 9, 10, 11, 12 → mono-jack mechanical switches (5 switches)
//       ✓  ESP32S3FH4R2 has in-package flash; this GPIO range is NOT
//          wired to any external chip, so these pads are free GPIO.
//     GPIO 13 → unused / free, available for future expansion
//
//   GPIO 48 → NeoPixel RGB LED (onboard, shared with red power LED)
//
// I2C / proximity-sensor support has been fully removed from this
// scaffold. GPIO 8 (former SDA) and GPIO 9 (former SCL) are now plain
// switch inputs, alongside GPIO 10, 11, and 12.
//
// 11 unique HID keycodes: F1–F6 (touch) and F9–F13 (switch), no
// modifier byte needed.
// All inputs fire on activation EDGE only (debounced, 35 ms).
// LED fades to off 250 ms after last event.
// =====================================================================

#include <NimBLEDevice.h>
#include <NimBLEHIDDevice.h>
#include <HIDKeyboardTypes.h>
#include <Adafruit_NeoPixel.h>

#include "types_expanded.h"

// =====================================================================
// HARDWARE — PIN MAP
// =====================================================================

// ── TTP223 capacitive touch (INPUT, active HIGH, no pull needed) ──────
static const uint8_t TOUCH_PINS[] = { 1, 2, 4, 5, 6, 7 };  // GPIO 3 skipped (strapping pin)
static constexpr uint8_t NUM_TOUCH = 6;

// ── Mono-jack switches (INPUT_PULLUP, active LOW) ─────────────────────
static const uint8_t SWITCH_PINS[] = { 8, 9, 10, 11, 12 };
static constexpr uint8_t NUM_SWITCH = 5;

// ── NeoPixel ─────────────────────────────────────────────────────────
#define LED_PIN    48
#define NUM_PIXELS 1

// =====================================================================
// HID KEYCODE LOOKUP TABLES  (F1–F6, F9–F13, all unique, no modifier needed)
// =====================================================================
//  id  GPIO  Source   Keycode  Key   LED Color
//   0     1  TOUCH    0x3A     F1    GREEN
//   1     2  TOUCH    0x3B     F2    GREEN
//   2     4  TOUCH    0x3C     F3    GREEN
//   3     5  TOUCH    0x3D     F4    GREEN
//   4     6  TOUCH    0x3E     F5    GREEN
//   5     7  TOUCH    0x3F     F6    GREEN
//   0     8  SWITCH   0x42     F9    BLUE
//   1     9  SWITCH   0x43     F10   BLUE
//   2    10  SWITCH   0x44     F11   BLUE
//   3    11  SWITCH   0x45     F12   BLUE
//   4    12  SWITCH   0x68     F13   BLUE
//
// LED color indicates INPUT TYPE, not individual sensor:
//   GREEN = any touch sensor (F1-F6)   BLUE = any switch input (F9-F13)
//   OFF   = idle

static const uint8_t TOUCH_KEYS[]    = { 0x3A, 0x3B, 0x3C, 0x3D, 0x3E, 0x3F };
static const uint8_t SWITCH_KEYS[]   = { 0x42, 0x43, 0x44, 0x45, 0x68 };
static const Color   TOUCH_COLORS[]  = { GREEN, GREEN, GREEN, GREEN, GREEN, GREEN };
static const Color   SWITCH_COLORS[] = { BLUE, BLUE, BLUE, BLUE, BLUE };

// =====================================================================
// GLOBALS
// =====================================================================
Adafruit_NeoPixel pixel(NUM_PIXELS, LED_PIN, NEO_GRB + NEO_KHZ800);

Color   ledCurrent = {0, 0, 0};
Color   ledTarget  = {0, 0, 0};
UIState ui;

const uint32_t DEBOUNCE_MS = 35;

DebouncedBtn t[NUM_TOUCH];
DebouncedBtn s[NUM_SWITCH];

NimBLEHIDDevice*      hid;
NimBLECharacteristic* input;
bool connected = false;

// =====================================================================
// BLE SERVER CALLBACKS
// =====================================================================
class ServerCallbacks : public NimBLEServerCallbacks {
  void onConnect(NimBLEServer* pServer, NimBLEConnInfo& connInfo) override {
    connected = true;
    Serial.println("=== CONNECTED ===");
  }
  void onDisconnect(NimBLEServer* pServer, NimBLEConnInfo& connInfo, int reason) override {
    connected = false;
    Serial.println("=== DISCONNECTED, restarting advertising ===");
    NimBLEDevice::startAdvertising();
  }
};

// =====================================================================
// LED FADE ENGINE
// =====================================================================
void fadeStep() {
  auto step = [](uint8_t &c, uint8_t tgt) {
    if (c < tgt) c++;
    else if (c > tgt) c--;
  };
  step(ledCurrent.r, ledTarget.r);
  step(ledCurrent.g, ledTarget.g);
  step(ledCurrent.b, ledTarget.b);
  pixel.setPixelColor(0, pixel.Color(ledCurrent.r, ledCurrent.g, ledCurrent.b));
  pixel.show();
}

// =====================================================================
// DEBOUNCE — returns true on stable-state change only
// =====================================================================
bool updateBtn(DebouncedBtn &b, bool raw) {
  uint32_t now = millis();
  if (raw != b.last) { b.last = raw; b.t = now; }
  if ((now - b.t) > DEBOUNCE_MS && b.stable != raw) {
    b.stable = raw;
    return true;
  }
  return false;
}

// =====================================================================
// HID KEY SEND  (press + release)
// =====================================================================
void sendKey(uint8_t modifier, uint8_t keycode) {
  if (!connected) { Serial.println("  (not connected, skipping)"); return; }

  uint8_t press[9]   = { 0x01, modifier, 0x00, keycode, 0x00, 0x00, 0x00, 0x00, 0x00 };
  uint8_t release[9] = { 0x01, 0x00,     0x00, 0x00,    0x00, 0x00, 0x00, 0x00, 0x00 };

  input->setValue(press, sizeof(press));
  input->notify();
  delay(30);
  input->setValue(release, sizeof(release));
  input->notify();
  delay(20);
}

// =====================================================================
// EVENT HANDLERS
// =====================================================================
void handleTouch(uint8_t id) {
  ui.lastEvent   = millis();
  ui.targetColor = TOUCH_COLORS[id];
  Serial.printf("TOUCH  %d  GPIO%-2d -> F%d (0x%02X)\n",
                id, TOUCH_PINS[id], id + 1, TOUCH_KEYS[id]);
  sendKey(0x00, TOUCH_KEYS[id]);
}

void handleSwitch(uint8_t id) {
  ui.lastEvent   = millis();
  ui.targetColor = SWITCH_COLORS[id];
  Serial.printf("SWITCH %d  GPIO%-2d -> F%d (0x%02X)\n",
                id, SWITCH_PINS[id], id + 9, SWITCH_KEYS[id]);
  sendKey(0x00, SWITCH_KEYS[id]);
}
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

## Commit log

2026-09-27 Synchronize README with production RB Switch
2026-09-27 Mark legacy adaptive-switch README as archived
2026-09-27 added documentation to github pages
    [enclosure.scad]
2026-09-28 added new lid types for enclosure for multiple student needs
    [enclosure.scad, enclosure_bar.stl, enclosure_base.stl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]
2026-09-28 adding BOM for different sites
    [BT_Switch_Mechanical_BOM.xlsx, BT_Switch_Mechanical_RevD.kicad_pcb, BT_Switch_Mechanical_RevD.kicad_sch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]
2026-09-29 Add sourced RevD BOM and CPL files
    [GH_RB_SWITCH_RevD_JLCPCB_BOM.xlsx, GH_RB_SWITCH_RevD_PCBWay_BOM.xlsx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]
2026-09-29 Include THT placements in JLCPCB CPL
    [GH_RB_SWITCH_RevD_JLCPCB_CPL.xlsx]
2026-09-29 added a lot of features and diagrams into the electrical folder
    [BT_Switch_Mechanical_BOM.xlsx, BT_Switch_Mechanical_RevD.kicad_pcb, BT_Switch_Mechanical_RevD.kicad_sch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]
2026-09-29 altered scad files
    [assistive_switch_storage_box.scad]
2026-09-29 corrected gerber files
    [BT_Switch_Mechanical_RevD.kicad_pcb, BT_Switch_Mechanical_RevD.kicad_sch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]
2026-09-29 corrected scad files for gerber orientation
2026-10-02 fixed schematic and pcb errors
    [GH_RB_SWITCH_RevD_JLCPCB_BOM.xlsx, GH_RB_SWITCH_RevD_PCBWay_BOM.xlsx, RB_Switch.kicad_pcb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]
2026-10-03 clean gerners now
    [BT_Switch_Mechanical_BOM.xlsx, GENERIC_RB_Switch_Mechanical_BOM.xlsx, RB_SWITCH_RevD_JLCPCB_BOM.xlsx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]
2026-10-04 gerbers, pcb, and sch all correct now. Improved docs
    [BT_Switch_Mechanical_BOM.xlsx, GENERIC_RB_Switch_Mechanical_BOM.xlsx, RB_SWITCH_RevD_JLCPCB_BOM.xlsx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]
2026-10-07 added better documentation
    [RB_Switch-B_Cu.gbl, RB_Switch-B_Mask.gbs, RB_Switch-Edge_Cuts.gm1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]

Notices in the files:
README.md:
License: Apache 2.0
